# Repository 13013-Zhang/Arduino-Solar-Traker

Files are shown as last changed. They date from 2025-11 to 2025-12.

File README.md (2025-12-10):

Read this in other languages: [English](README.md), [中文](README_ZH.md).

# ES2C6-Solar-Tracker






This is a solar tracker repository for the ES2C6 course. This project includes two distinct Arduino implementations to demonstrate and compare different solar tracking strategies.

1.  **Simple LDR**: A pure "active" tracker that uses four LDRs (Light Dependent Resistors) to find the brightest light source.
2.  **Advanced Hybrid + Web UI Tracker**: A "hybrid" tracker that uses an Arduino R4 WiFi to fetch precise UTC time, calculate the sun's astronomical position (azimuth/elevation), and then uses LDRs for fine-tuning. It also hosts a modern Web UI for status monitoring.

### Circuit
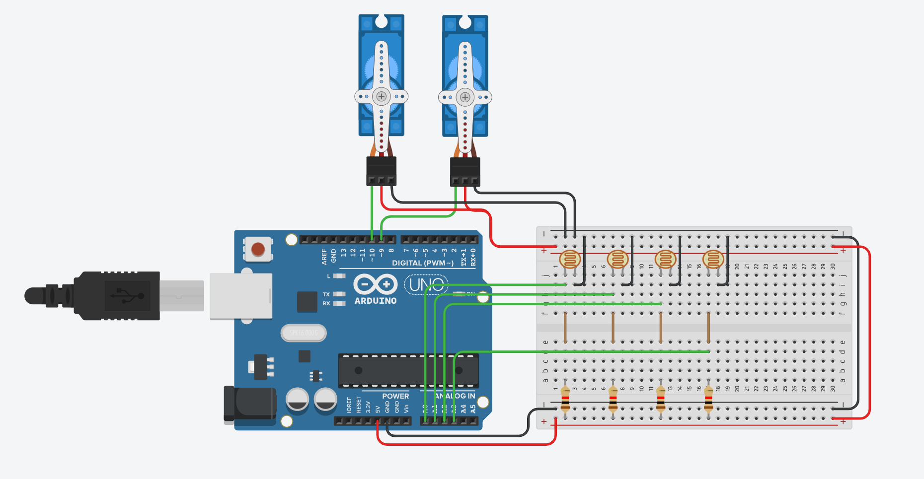
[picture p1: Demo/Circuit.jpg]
Circuit

Schematic

---

## 1. Simple LDR LED Tracker

This is a classic "active" solar tracker. It doesn't care about time or location; it only cares where the light is coming from.

### ✨ Features

* **Active Tracking**: Purely based on the difference in readings from the four LDRs to move the servos, always pointing towards the brightest direction.
    * Solar panel voltage
    * Raw readings of the 4 LDRs
    * Current servo angles (Horizontal/Vertical)
    * Average light intensity
* **Startup Scan**: Executes a `findMaxLightPosition()` function on boot, scanning the sky (0-180 degrees) to find the initial brightest spot.
* **Voltage Monitoring**: Optionally connect a small solar panel to pin `A4` to monitor its output voltage.

### 🛠️ Hardware Requirements

* Arduino Uno / Nano (or any compatible board)
* 2x Servo Motors (for Pan/Tilt)
* 4x LDRs (Light Dependent Resistors)
* 4x Pull-down Resistors (e.g., 10KΩ)
* 1x Small Solar Panel (for A4 pin reading)
* 2-axis Pan/Tilt bracket
* Breadboard and jumper wires

### 📚 Library Dependencies

* `Servo`
* `Adafruit_SSD1306`
* `Adafruit_GFX`

### 🔧 Setup and Usage

1.  Download the code into the `Codes/sdynamic_Step/` folder.
2.  Open `sdynamic_Step.ino` in the Arduino IDE.
3.  Install the `Adafruit_SSD1306` and `Adafruit_GFX` libraries using the Library Manager.
4.  **Check Pins**: Ensure your OLED and servo pin definitions match the `#define` section at the top of the code.
    * OLED (SPI): `OLED_MOSI`, `OLED_CLK`, `OLED_DC`, `OLED_CS`, `OLED_RESET`
    * Servos: `5` (horizontal), `6` (vertical)
    * LDRs: `A0` (TL), `A1` (TR), `A2` (BL), `A3` (BR)
    * Solar Panel: `A4`
5.  Upload the code to your Arduino.
6.  When the device boots, it will first perform a "find max light" scan. The OLED will then light up with real-time data, and the tracker will begin active tracking.

### Demo
- not assembled  
Solar Tracker

---

## 2. Advanced Hybrid + Web UI Tracker

This version uses an Arduino R4 WiFi board, combining time-based predictive tracking with LDR-based corrective tracking.

### ✨ Features

* **Hybrid Tracking**:
    * **Predictive**: Connects to `worldtimeapi.org` to get UTC time and accurately calculates the sun's Azimuth and Elevation based on a given Latitude and Longitude.
    * **Corrective**: Uses a 4-quadrant LDR sensor array to fine-tune the calculated position, compensating for any misalignments or atmospheric effects.
* **Web Console**: Hosts a web server that provides a modern, responsive dashboard built with Tailwind CSS.
* **Solunar API**: Fetches the day's sunrise, sunset, and solar noon times from `api.sunrise-sunset.org`.
* **Night Mode**: Automatically enters "Night Mode" when the sun's elevation is below a threshold (e.g., after sunset), moving the servos to a preset night position (e.g., facing east, ready for sunrise).
* **WiFi Management**: Automatically attempts to reconnect to WiFi if the connection is lost.

### 🛠️ Hardware Requirements

* Arduino R4 WiFi
* 2x Servo Motors (for Pan/Tilt)
* 4x LDRs (Light Dependent Resistors)
* 4x Pull-down Resistors (e.g., 10KΩ)
* 2-axis Pan/Tilt bracket
* Breadboard and jumper wires

### 📚 Library Dependencies

* `WiFiS3`
* `ArduinoJson`
* `Servo`

### 🔧 Setup and Usage

1.  Download the code into the `Codes/Dynamic_Step_wtih_Website/` folder.
2.  Open `dynamic_Step_wtih_Website.ino` in the Arduino IDE.
3.  Install the required libraries using the Library Manager.
4.  **Crucial Configuration**: Modify the constants at the top of the sketch:
    * `WIFI_SSID`: Your WiFi network name.
    * `WIFI_PASS`: Your WiFi password.
    * `LATITUDE`: Your geographic latitude (e.g., `52.378753f`).
    * `LONGITUDE`: Your geographic longitude (e.g., `-1.570225f`).
5.  Upload the code to your Arduino R4 WiFi.
6.  Open the **Serial Monitor** (Baud Rate: 115200) to view the connection status and the IP address.
7.  On a device on the same network, open a web browser and navigate to that IP address (e.g., `http://192.168.31.166`) to see the web console.

### Demo
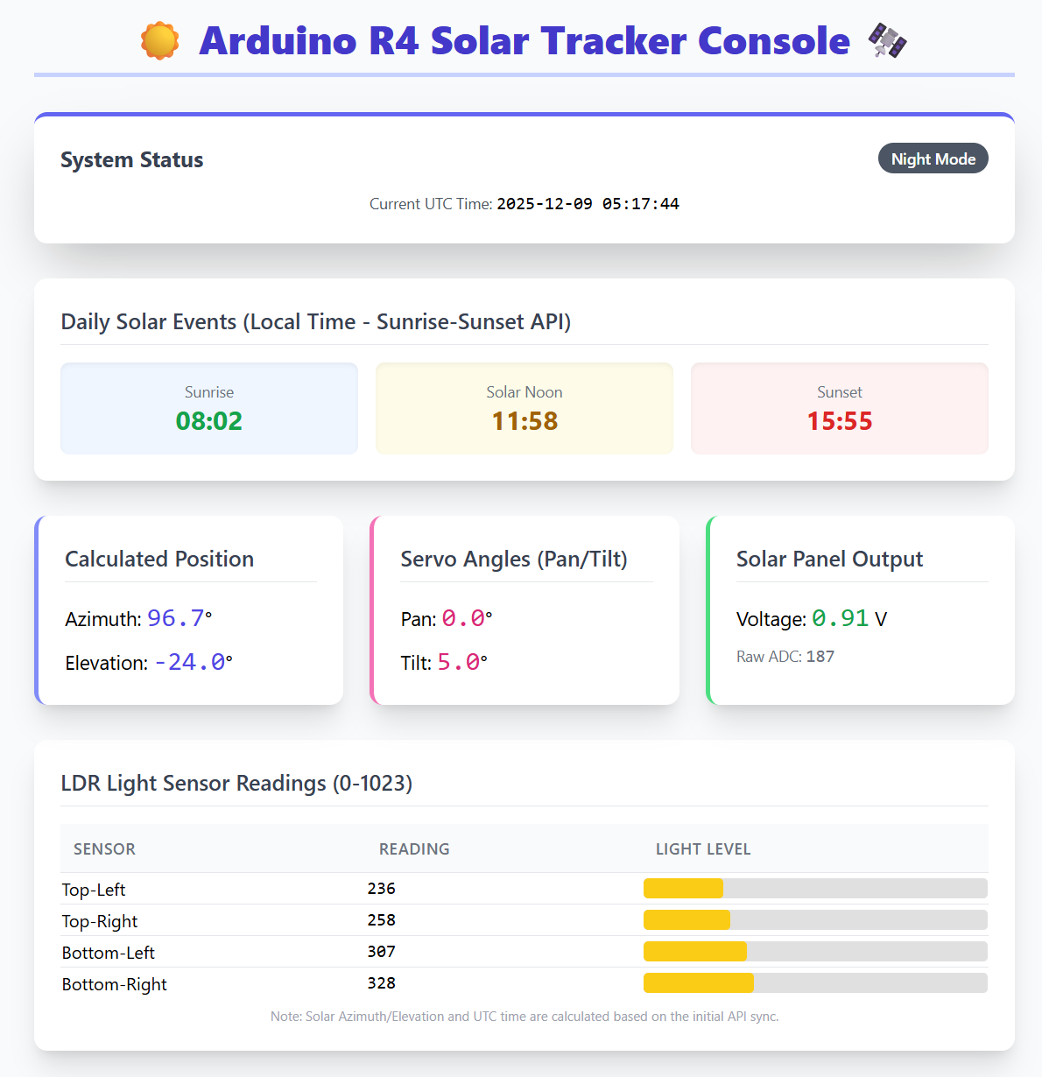
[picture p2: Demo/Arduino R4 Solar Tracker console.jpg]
Solar Tracker


---

## 💡 How It Works

### Active Tracker (Simple)

This model uses a simple **Feedback Loop**:

1.  Compare the average of the top LDRs vs. the average of the bottom LDRs (`diffVertical`).
2.  Compare the average of the left LDRs vs. the average of the right LDRs (`diffHorizontal`).
3.  If the vertical difference is greater than the `tolerance`, move the vertical servo up or down.
4.  If the horizontal difference is greater than the `tolerance`, move the horizontal servo left or right.
5.  This process repeats, constantly minimizing the LDR differences to stay pointed at the light source.

### Hybrid Tracker (Advanced)

This model uses a **Predict-Correct** loop:

1.  **Predict (Every 10 seconds)**: The device gets the precise time from an API and uses the `solarPositionUTC` function to calculate the sun's *theoretical* position in the sky (azimuth/elevation).
2.  **Correct (Every 50 milliseconds)**:
    * The LDRs read the light differential (`azDiff`, `elDiff`).
    * The new target position for the servo is a combination of **(LDR correction) + (a gentle pull towards the theoretical position)**.
    * `currentPan += deltaPan + SOLAR_CORRECTION_RATE * (targetPanFromSolar - currentPan);`
    * This ensures the tracker not only points accurately at the sun (LDR part) but also knows where the sun *should* be, even after it's temporarily hidden by clouds (time-based part).

---

## 🎉 Acknowledgements / Group Members

This project was a collaborative effort for the ES2C6 module, and the successful outcome is a result of the dedicated work of the entire team. We extend our sincere thanks to the following members:

| Name | Assigned Role |
| :--- | :--- |
| Monteiro, Marcus | Background Research |
| Zhao, Haoxiang Owen | Mechanical Design and CAD Work |
| Jackson, Josh | Electronic Design |
| Stephan, Freddy | Manufacture of Mechanical Components and Electronic Circuit Boards |
| Maini, Rohan | Assembly |
| Boyu Zhang Bob (me) | Programming and Testing |
| Charusirisawad, Pun | Overall Project Management and Assigned Task Lead |

---

## 📄 License

This project is licensed under the [MIT License](LICENSE). You should add a `LICENSE` file to your repository.

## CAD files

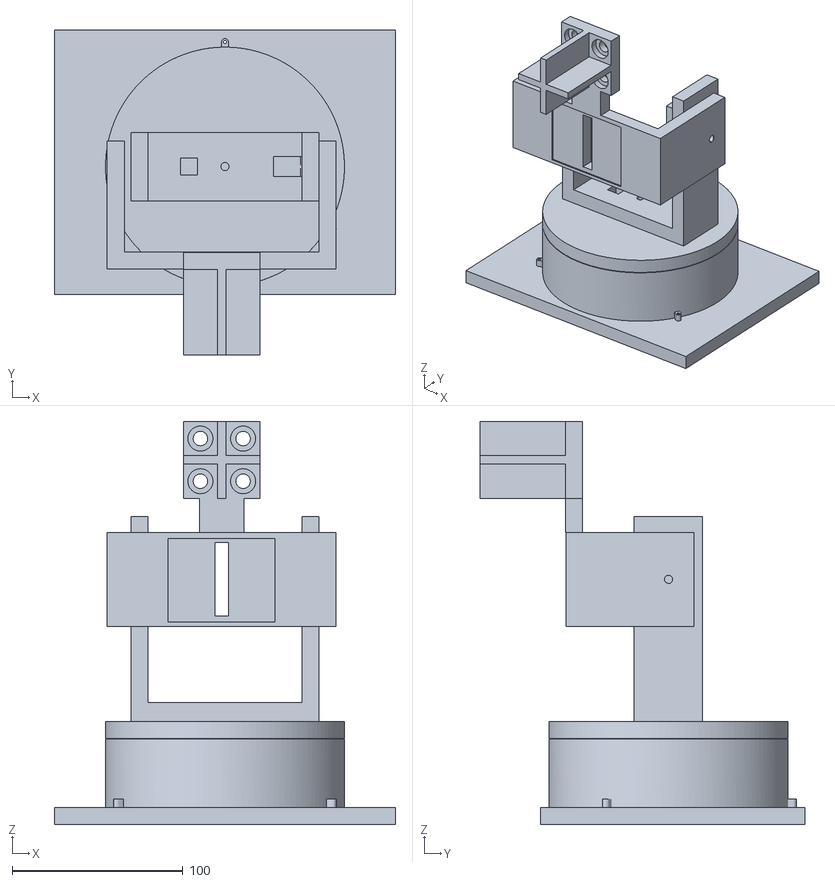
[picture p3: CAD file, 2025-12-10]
3D Printing/Demo 3/Complete.stl
200.0 x 190.4 x 236.1

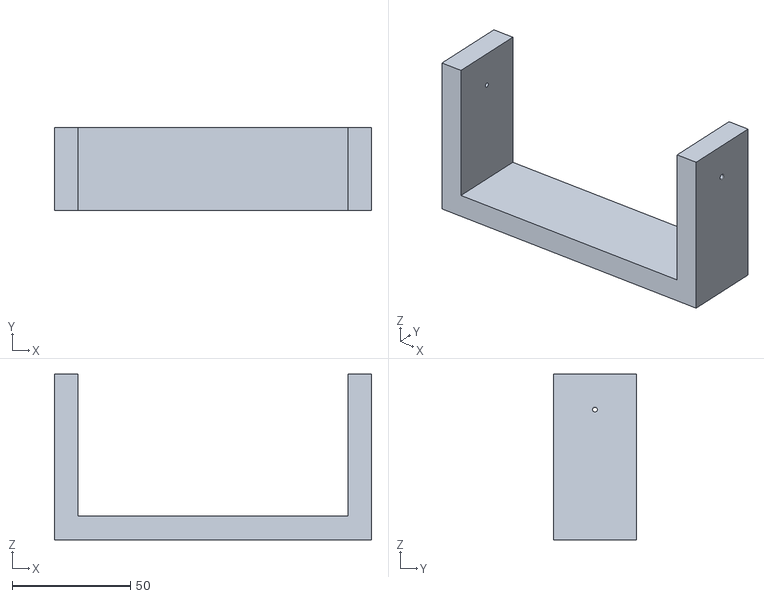
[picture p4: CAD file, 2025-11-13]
3D Printing/Demo 1/Solar Platform.stl
134.0 x 35.0 x 70.0

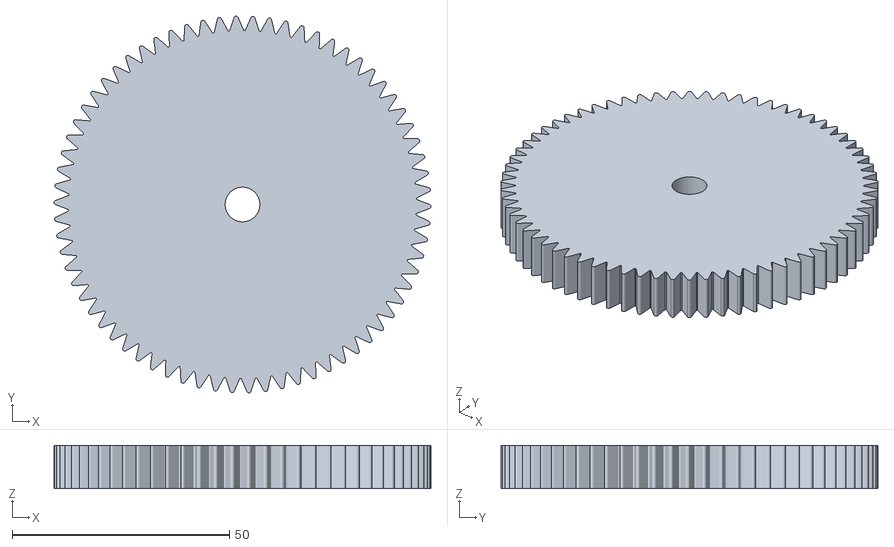
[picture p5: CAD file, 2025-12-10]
3D Printing/Demo 2 Change/Gear median 1 1.stl
86.7 x 86.6 x 10.0

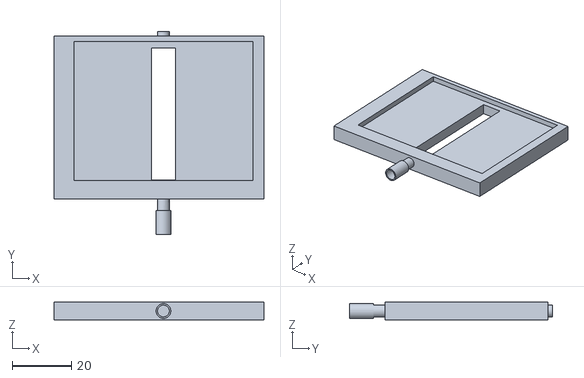
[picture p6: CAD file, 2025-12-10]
3D Printing/Demo 2/Solar Platform Leftside 2. NEW stl.stl
71.0 x 68.5 x 6.00

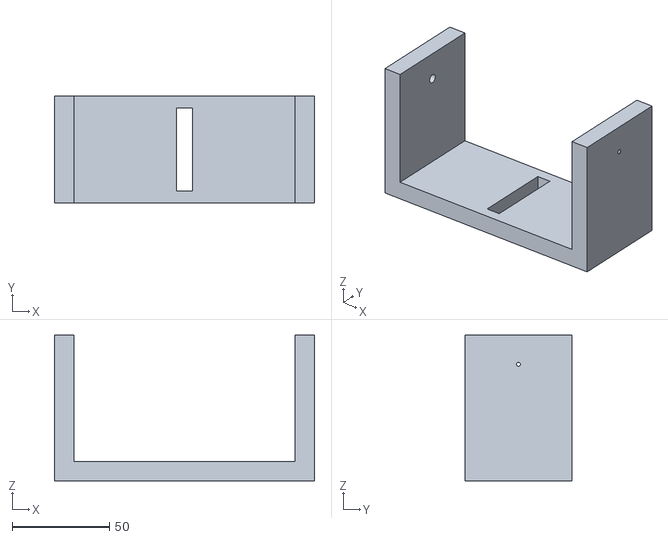
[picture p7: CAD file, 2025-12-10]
3D Printing/Demo 3/Solar Platform 1.stl
134.0 x 55.0 x 75.0

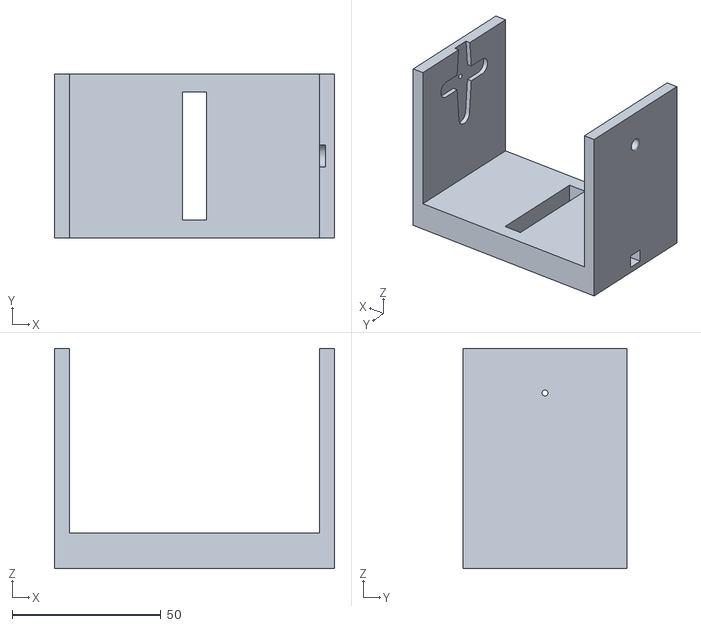
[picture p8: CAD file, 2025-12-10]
3D Printing/Final 1/Solar Platform 2.stl
94.0 x 55.0 x 74.0

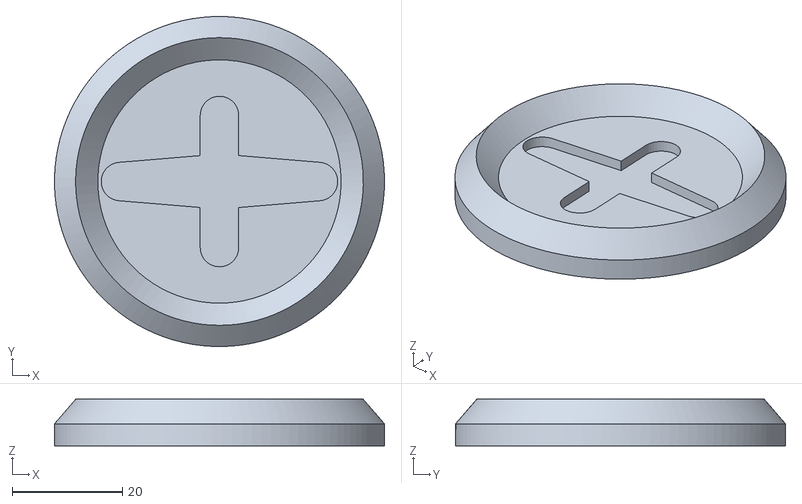
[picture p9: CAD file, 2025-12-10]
3D Printing/Final 2/Base.stl
60.0 x 60.0 x 8.46

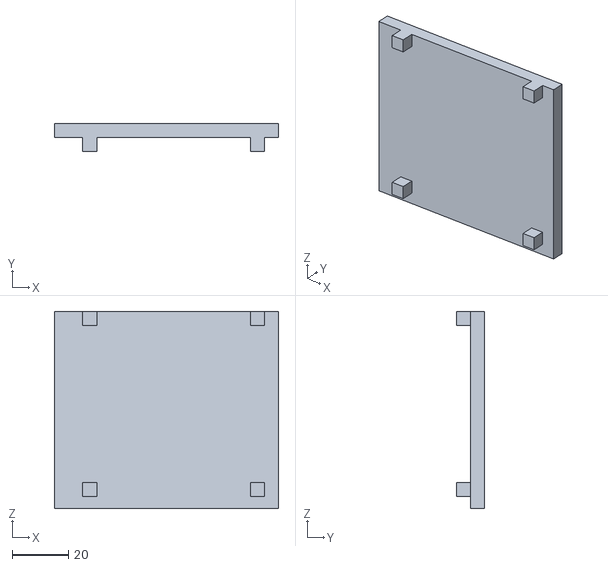
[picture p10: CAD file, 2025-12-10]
3D Printing/Final 3/Walls.stl
79.5 x 10.0 x 70.0

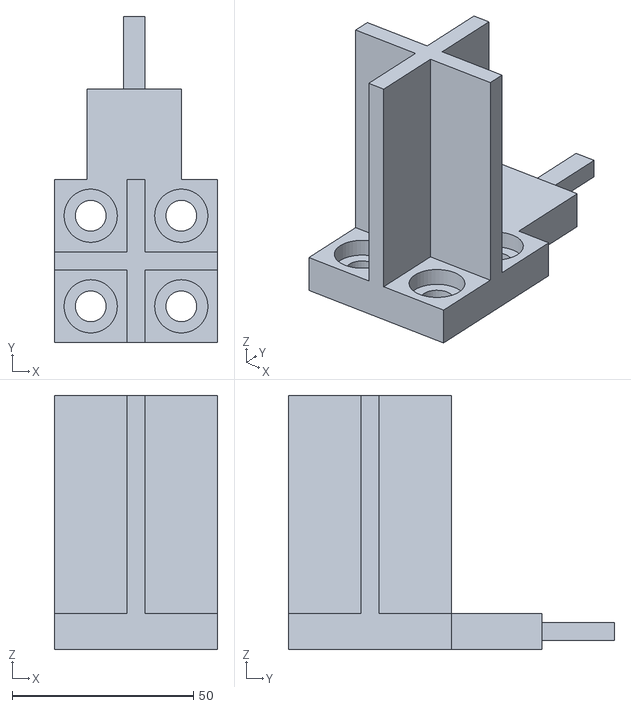
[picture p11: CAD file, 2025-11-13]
3D Printing/Demo 1/LDR Platform.stl
45.0 x 90.0 x 70.1

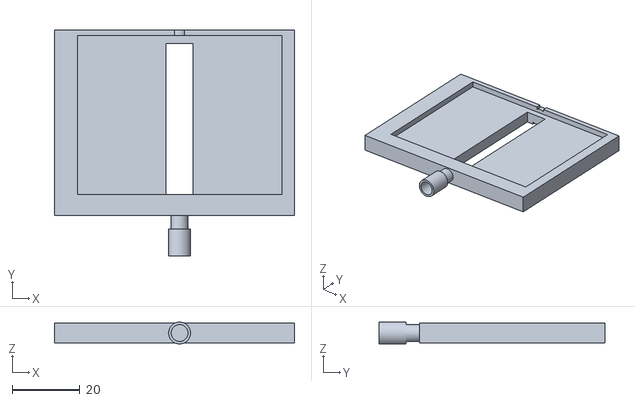
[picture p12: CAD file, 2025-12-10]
3D Printing/Demo 2 Change/Solar Platform Leftside 2 2.stl
71.0 x 67.0 x 6.49

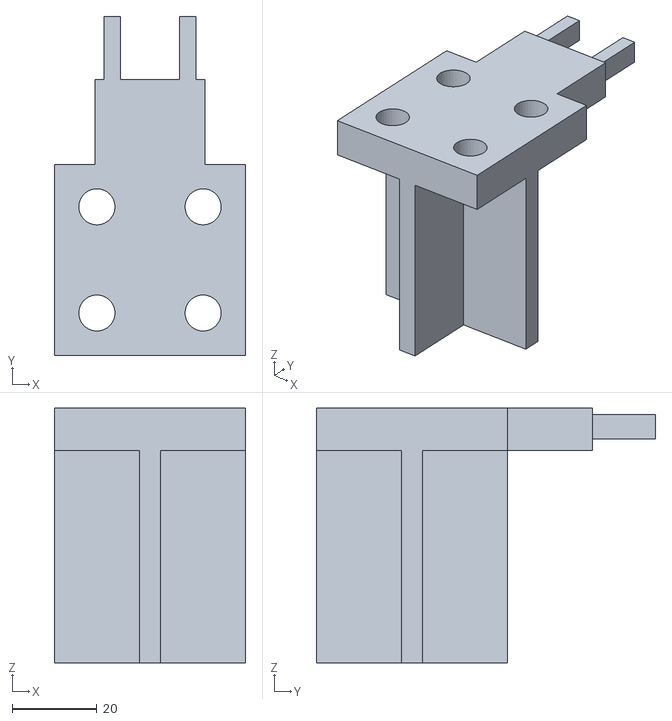
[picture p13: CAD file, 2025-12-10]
3D Printing/Demo 3/LDR.stl
45.0 x 79.8 x 60.0

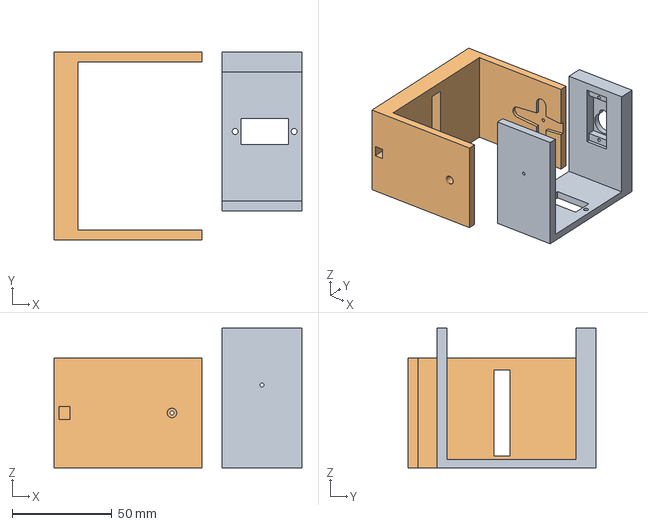
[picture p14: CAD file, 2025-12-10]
3D Printing/Final 1/Final 1.3mf
124.0 x 94.0 x 70.0 mm
Motor circuling Platform 2.stl
Solar Platform 2.stl

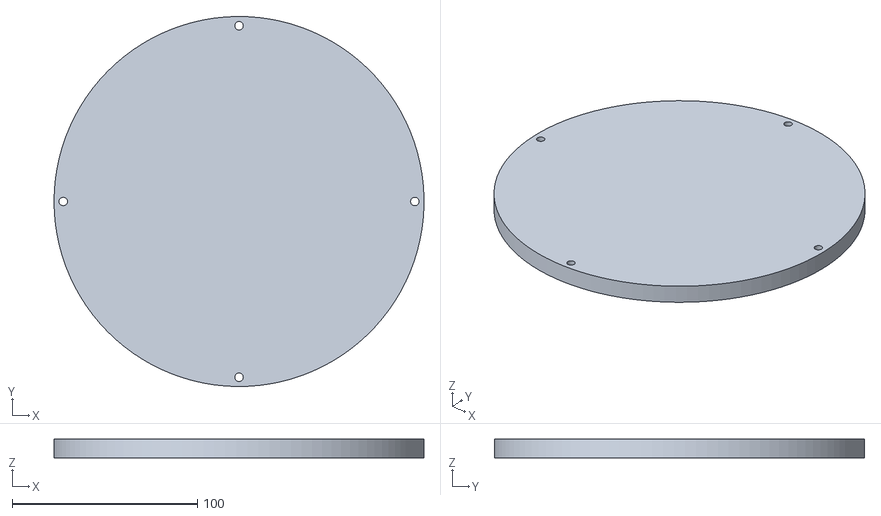
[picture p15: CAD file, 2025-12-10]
3D Printing/Final 2/Lower Base Connector.stl
200.0 x 200.0 x 10.0

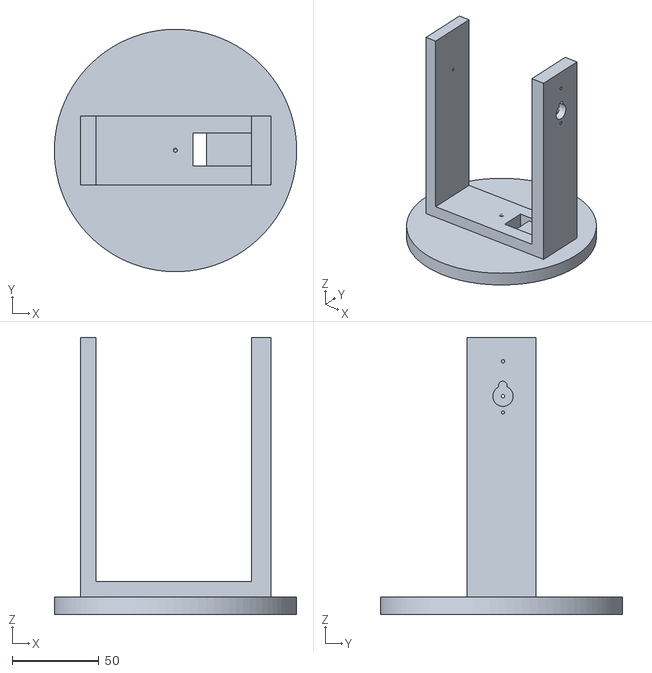
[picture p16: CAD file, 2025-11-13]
3D Printing/Demo 1/Motor circuling Platform.stl
140.0 x 140.0 x 160.0

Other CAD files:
3D Printing/Demo 2/Solar Platform Leftside 2 1.stl
3D Printing/Final 3/Walls 2.stl
3D Printing/Demo 2 Change/Demo 2 Changed.3mf
3D Printing/Demo 2/LDR Platform Part1 1.stl
3D Printing/Demo 1/LDR Platform.f3d
3D Printing/Demo 1/Motor circuling Platform.f3d
3D Printing/Demo 1/Solar Platform First Edition.3mf
3D Printing/Demo 1/Solar Platform.f3d
3D Printing/Demo 1/Under Platform.f3d
3D Printing/Demo 1/Under Platform.stl
3D Printing/Demo 2 Change/sleve 1.stl
3D Printing/Demo 2/Advancce Edition Motor Platform 1.stl
3D Printing/Demo 2/Demo 2.3mf
3D Printing/Demo 2/First class connecting bar 1.stl
3D Printing/Demo 2/Gear median 1.stl
3D Printing/Demo 2/Gear median thicker 1.stl
3D Printing/Demo 2/LDR Platform Part1 1 1.stl
3D Printing/Demo 2/Solar Platform Leftside 2.stl
3D Printing/Demo 2/Upper Connecting Bar 1.stl
3D Printing/Demo 2/sleve 2.stl
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

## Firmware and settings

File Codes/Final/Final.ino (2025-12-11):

#include <WiFiS3.h> // For Uno R4 WiFi
#include <WiFiClient.h>
#include <WiFiServer.h>
#include <ArduinoJson.h>
#include <Servo.h>

// ----------------------------------------------------------------------------
// 1. CONFIGURATION CONSTANTS
// ----------------------------------------------------------------------------

const char* WIFI_SSID = "Redmi K70 Ultra";
const char* WIFI_PASS = "20050215";


const float LATITUDE = 34.0522; 
const float LONGITUDE = -118.2437; 

// API Hostnames
const char* TIME_HOST = "worldtimeapi.org"; 
const char* SOLUNAR_HOST = "api.sunrise-sunset.org"; 


// LDRs
const int LDR_TL = A0; // Top-Left
const int LDR_TR = A1; // Top-Right
const int LDR_BL = A2; // Bottom-Left
const int LDR_BR = A3; // Bottom-Right
// Solar Panel Voltage Sensor
const int SOLAR_PANEL_PIN = A4; 
// Servos
const int HORIZONTAL_SERVO_PIN = 6; // Pan Servo
const int VERTICAL_SERVO_PIN = 5;   // Tilt Servo
// Manual Override Pin (Low to disable tracking)
const int SERVOS_OFF_PIN = 7; 


// ----------------------------------------------------------------------------
// 2. DATA STRUCTURES
// ----------------------------------------------------------------------------


struct TimeData {
    int Y = 0, M = 0, D = 0, h = 0, min = 0, s = 0;
    String iso_sync = ""; 

    String toString() const {
        char buf[20];
        sprintf(buf, "%04d-%02d-%02d %02d:%02d:%02d", Y, M, D, h, min, s);
        return String(buf);
    }
};

struct SolarAngles {
    float azimuth = 0.0;
    float elevation = 0.0;
};

struct SolunarData {
    String sunrise = "--:--";
    String sunset = "--:--";
    String solarnoon = "--:--";
    int lastFetchDay = 0;
};

// ----------------------------------------------------------------------------
// 3. GLOBAL STATE
// ----------------------------------------------------------------------------

// Web Server
WiFiServer server(80);


TimeData g_currentTime;
SolunarData dailySolunar;
SolarAngles lastSolar; 

Servo horizontalServo;
Servo verticalServo;


int sensitivity = 50; 
const int minStepSize = 2; 


int horizontalPos = 90;
int verticalPos = 90;

int tl = 0;
int tr = 0;
int bl = 0;
int br = 0;

// 太阳能板读数
float slr = 0;
float slrTrue = 0;

// 翻转逻辑 (Flip Timer)
int count = 0;
unsigned long stuckTimerStart = 0;
const int waitTime = 1000; // 1秒等待时间
const int cooldown = 1000; // 1秒冷却时间
unsigned long cooldownStarted = 0;

// 日落逻辑 (Sunset Timer)
int sunsetAngle = 20; // 仰角小于此值时开始判断
int LDRavg = 0;
int sunsetDarkness = 850; // 平均 LDR 读数大于此值时认为天黑
int countSunset = 0;
unsigned long sunsetTimer = 0;
const int sunsetWait = 5000; // 5秒等待时间
const int pauseTimer = 250; // 暂停时间
unsigned long currentTime = 0;


// ----------------------------------------------------------------------------
// 4. UTILITY FUNCTIONS (辅助函数)
// ----------------------------------------------------------------------------

float deg2rad(float deg) {
    return deg * (PI / 180.0);
}

float rad2deg(float rad) {
    return rad * (180.0 / PI);
}

// LDR 读取辅助函数
int readLDR(int pin) {
    return analogRead(pin);
}

// 儒略日计算 (简化版，适用于粗略太阳位置计算)
double calcJulianDay(int Y, int M, int D, int h, int min, int s) {
    double D_h = D + (h + min / 60.0 + s / 3600.0) / 24.0;
    if (M <= 2) {
        Y -= 1;
        M += 12;
    }
    double A = floor(Y / 100.0);
    double B = 2 - A + floor(A / 4.0);
    return floor(365.25 * (Y + 4716)) + floor(30.6001 * (M + 1)) + D_h + B - 1524.5;
}

// 12小时制时间转换为24小时制 HH:MM
String convert12hTo24h(String time12h) {
    if (time12h == "") return "--:--";
    time12h.trim();
    int spaceIndex = time12h.indexOf(' ');
    String timePart = time12h.substring(0, spaceIndex);
    String ampmPart = time12h.substring(spaceIndex + 1);

    int colonIndex = timePart.indexOf(':');
    int hour = timePart.substring(0, colonIndex).toInt();
    int minute = timePart.substring(colonIndex + 1, colonIndex + 3).toInt(); // Extract minutes up to the second colon if seconds exist

    if (ampmPart == "PM" && hour != 12) {
        hour += 12;
    } else if (ampmPart == "AM" && hour == 12) {
        hour = 0; // Midnight 12 AM is 00
    }

    char buf[6];
    sprintf(buf, "%02d:%02d", hour, minute);
    return String(buf);
}


// ----------------------------------------------------------------------------
// 5. SOLAR POSITION CALCULATION (太阳位置计算)
// ----------------------------------------------------------------------------

// 计算给定UTC时间的太阳方位角和仰角 (基于 NOAA 算法的简化版)
SolarAngles solarPositionUTC(const TimeData& t, float lat, float lon) {
    // 您的太阳角度计算逻辑
    double jd = calcJulianDay(t.Y, t.M, t.D, t.h, t.min, t.s);
    double n = jd - 2451545.0;
    double L = fmod(280.460 + 0.9856474 * n, 360.0);
    if (L < 0) L += 360.0;
    double g = fmod(357.528 + 0.9856003 * n, 360.0);
    if (g < 0) g += 360.0;
    double g_rad = deg2rad((float)g);
    double lambda = L + 1.915 * sin(g_rad) + 0.020 * sin(2 * g_rad);
    double lambda_rad = deg2rad((float)lambda);
    double eps = 23.439 - 0.0000004 * n;
    double eps_rad = deg2rad((float)eps);
    double alpha = atan2(cos(eps_rad) * sin(lambda_rad), cos(lambda_rad));
    double delta = asin(sin(eps_rad) * sin(lambda_rad));
    double JD0 = floor(jd + 0.5) - 0.5;
    double T = (JD0 - 2451545.0) / 36525.0;
    double GMST = fmod(280.46061837 + 360.98564736629 * (jd - 2451545.0) + 0.000387933 * T * T - (T * T * T) / 38710000.0, 360.0);
    if (GMST < 0) GMST += 360.0;
    double LST = fmod(GMST + lon, 360.0);
    if (LST < 0) LST += 360.0;
    double alpha_deg = rad2deg((float)alpha);
    if (alpha_deg < 0) alpha_deg += 360.0;
    double H = LST - alpha_deg;
    if (H < -180) H += 360;
    if (H > 180) H -= 360;
    double H_rad = deg2rad((float)H);
    double lat_rad = deg2rad(lat);
    double el_rad = asin(sin(lat_rad) * sin(delta) + cos(lat_rad) * cos(delta) * cos(H_rad));
    double elevation = rad2deg((float)el_rad);
    // 修正的方位角计算 atan2(sin(H), cos(H) * sin(lat) - tan(delta) * cos(lat))
    double az_rad = atan2(sin(H_rad), cos(H_rad) * sin(lat_rad) - tan(delta) * cos(lat_rad));
    double az_deg = rad2deg((float)az_rad);
    // 将方位角调整到 0 到 360 度范围，0度为北，180度为南 (NOAA标准: 南为0)
    // 转换为标准方位角 (北为0, 东为90)
    az_deg = az_deg + 180.0; 
    if (az_deg < 0) az_deg += 360.0;
    if (az_deg >= 360) az_deg -= 360.0;
    
    SolarAngles out;
    out.azimuth = (float)az_deg;
    out.elevation = (float)elevation;
    return out;
}


// ----------------------------------------------------------------------------
// 6. NETWORK AND API FUNCTIONS (网络与 API)
// ----------------------------------------------------------------------------

bool attemptReconnect(unsigned long timeout_ms) {
    if (WiFi.status() == WL_CONNECTED && WiFi.localIP() != IPAddress(0, 0, 0, 0)) {
        return true;
    }
    Serial.println("\nAttempting Wi-Fi reconnect...");
    WiFi.disconnect();
    WiFi.begin(WIFI_SSID, WIFI_PASS);
    unsigned long start = millis();
    while (WiFi.status() != WL_CONNECTED && millis() - start < timeout_ms) {
        delay(500);
        Serial.print("#");
    }
    if (WiFi.status() == WL_CONNECTED && WiFi.localIP() != IPAddress(0, 0, 0, 0)) {
        Serial.println("\nReconnect successful. IP: " + WiFi.localIP().toString());
        server.begin();
        return true;
    }
    Serial.println("\nWi-Fi reconnect failed.");
    return false;
}

bool fetchUTC(TimeData& t) {
    WiFiClient client;
    Serial.print("Attempting to connect to Time API (");
    Serial.print(TIME_HOST);
    Serial.print(")...");

    if (!client.connect(TIME_HOST, 80)) {
        Serial.println("Connection failed!");
        return false;
    }
    Serial.println("Success!");

    String req = "GET /api/ip HTTP/1.1\r\nHost: ";
    req += TIME_HOST;
    req += "\r\nConnection: close\r\n\r\n";
    client.print(req);

    unsigned long start = millis();
    while (!client.available() && millis() - start < 10000) delay(10);

    if (!client.available()) {
        Serial.println("API response timeout.");
        client.stop();
        delay(100);
        return false;
    }

    // Skip HTTP headers
    while (client.available()) {
        String line = client.readStringUntil('\n');
        if (line.length() < 3 && line.indexOf('\r') != -1) break;
    }

    String json = client.readString();
    client.stop();
    delay(100);

    if (json.length() < 50) {
        Serial.println("API response too short or invalid.");
        return false;
    }

    // 假设 DynamicJsonDocument size 足够
    DynamicJsonDocument doc(1024);
    DeserializationError error = deserializeJson(doc, json);

    if (error) {
        Serial.print("UTC JSON parsing error: ");
        Serial.println(error.c_str());
        return false;
    }

    if (!doc.containsKey("utc_datetime")) {
        Serial.println("UTC JSON missing 'utc_datetime' field.");
        return false;
    }

    String dt = doc["utc_datetime"].as<String>();
    // 格式: 2023-11-20T10:30:00.123456+00:00 (只取前19位)
    
    // 检查 T 在正确的位置
    if (dt.indexOf('T') != 10) {
        Serial.println("UTC datetime format error.");
        return false;
    }

    t.iso_sync = dt.substring(0, 19); 
    t.Y = dt.substring(0, 4).toInt();
    t.M = dt.substring(5, 7).toInt();
    t.D = dt.substring(8, 10).toInt();
    t.h = dt.substring(11, 13).toInt();
    t.min = dt.substring(14, 16).toInt();
    t.s = dt.substring(17, 19).toInt();

    Serial.print("Successfully synced UTC time: ");
    Serial.println(t.toString());
    return true;
}

bool fetchSolunar(const TimeData& t) {
    if (t.Y == 0) {
        Serial.println("Solunar Fetch: UTC time not synced, skipping fetch.");
        return false;
    }
    if (t.D == dailySolunar.lastFetchDay && dailySolunar.sunrise != "--:--") {
        Serial.println("Solunar Fetch: Data for today already fetched, skipping.");
        return true;
    }

    WiFiClient client;
    Serial.print("Attempting to connect to Solunar API (");
    Serial.print(SOLUNAR_HOST);
    Serial.print(")...");

    if (!client.connect(SOLUNAR_HOST, 80)) {
        Serial.println("Connection failed!");
        return false;
    }
    Serial.println("Success!");

    char dateStr[11];
    sprintf(dateStr, "%04d-%02d-%02d", t.Y, t.M, t.D);
    String latStr = String(LATITUDE, 7);
    String lngStr = String(LONGITUDE, 7);
    // API默认返回本地时间
    String path = "/json?lat=" + latStr + "&lng=" + lngStr + "&date=" + String(dateStr); 

    Serial.print("Solunar Request URL: http://");
    Serial.print(SOLUNAR_HOST);
    Serial.println(path);


    client.print("GET ");
    client.print(path);
    client.print(" HTTP/1.1\r\n");
    client.print("Host: " + String(SOLUNAR_HOST) + "\r\n");
    client.print("Connection: close\r\n\r\n");

    String json = "";
    unsigned long startJsonRead = millis();
    bool header_passed = false;

    while (client.connected() && millis() - startJsonRead < 8000) { // Timeout 8s
        if (client.available()) {
            String line = client.readStringUntil('\n');
            if (!header_passed) {
                if (line == "\r") { // End of headers
                    header_passed = true;
                }
            } else {
                json += line; // Start reading JSON body
            }
        } else {
            delay(10);
        }
    }
    client.stop();
    delay(100);
    
    // Attempt to find the first '{' to ensure clean JSON parsing
    int jsonStart = json.indexOf('{');
    if (jsonStart != -1) {
        json = json.substring(jsonStart);
    } else {
        Serial.println("API response missing JSON content.");
        return false;
    }


    Serial.print("Solunar RAW JSON (Length: ");
    Serial.print(json.length());
    Serial.println("):");
    // Serial.println(json); // 打印原始JSON可能太长，只打印长度

    if (json.length() < 50) {
        Serial.println("API response too short or invalid.");
        return false;
    }

    DynamicJsonDocument doc(2048);
    DeserializationError error = deserializeJson(doc, json);

    if (error) {
        Serial.print("Solunar JSON error: ");
        Serial.println(error.c_str());
        return false;
    }

    String status = doc["status"].as<String>();
    if (status != "OK" || !doc.containsKey("results")) {
        Serial.print("Solunar API returned non-OK status: ");
        Serial.println(status);
        return false;
    }

    // API 返回 12 小时制带 AM/PM 的时间
    String rawSunrise = doc["results"]["sunrise"].as<String>();
    String rawSunset = doc["results"]["sunset"].as<String>();
    String rawSolarNoon = doc["results"]["solar_noon"].as<String>();

    // 转换为 24 小时制 HH:MM
    dailySolunar.sunrise = convert12hTo24h(rawSunrise);
    dailySolunar.sunset = convert12hTo24h(rawSunset);
    dailySolunar.solarnoon = convert12hTo24h(rawSolarNoon);
    dailySolunar.lastFetchDay = t.D;

    Serial.println("Solunar data updated successfully (from api.sunrise-sunset.org)");
    return true;
}


// ----------------------------------------------------------------------------
// 7. WEB SERVER FUNCTIONS (Web 服务器)
// ----------------------------------------------------------------------------

String buildStatusJSON() {
    DynamicJsonDocument doc(1024);
    doc["lat"] = LATITUDE;
    doc["lon"] = LONGITUDE;

    if (g_currentTime.Y != 0) {
        // 由于 Arduino 没有实时RTC，所以时间只是首次同步的值
        doc["utc"] = g_currentTime.toString(); 
        doc["timestamp_sync"] = g_currentTime.iso_sync; 
    } else {
        doc["utc"] = "Time Sync Failed";
    }

    // 强制设置为 LDR 跟踪模式
    doc["mode"] = "LDR Tracking Mode (Always Active)"; 

    // 天文数据 (初始计算值)
    doc["solar"]["azimuth"] = roundf(lastSolar.azimuth * 10.0f) / 10.0f;
    doc["solar"]["elevation"] = roundf(lastSolar.elevation * 10.0f) / 10.0f;

    // 日出日落数据
    doc["solunar"]["sunrise"] = dailySolunar.sunrise;
    doc["solunar"]["sunset"] = dailySolunar.sunset;
    doc["solunar"]["solarnoon"] = dailySolunar.solarnoon;

    // 伺服角度 (使用控制逻辑中的实时位置)
    doc["servos"]["pan"] = roundf(horizontalPos * 10.0f) / 10.0f;
    doc["servos"]["tilt"] = roundf(verticalPos * 10.0f) / 10.0f;

    // LDR 读数
    doc["ldr"]["tl"] = tl;
    doc["ldr"]["tr"] = tr;
    doc["ldr"]["bl"] = bl;
    doc["ldr"]["br"] = br;

    // 太阳能板输出
    doc["solar_panel"]["voltage"] = roundf(slrTrue * 100.0f) / 100.0f;
    doc["solar_panel"]["raw"] = (int)slr;

    String out;
    serializeJson(doc, out);
    return out;
}

void handleClient(WiFiClient client) {
    // Web Server HTML/JSON 逻辑
    String req = client.readStringUntil('\r');
    if (req.length() < 2) {
        client.stop();
        return;
    }
    int sp1 = req.indexOf(' '), sp2 = req.indexOf(' ', sp1 + 1);
    String path = req.substring(sp1 + 1, sp2);
    
    // Read the rest of the HTTP request headers
    while (client.available()) {
        String line = client.readStringUntil('\n');
        if (line == "\r") break;
    }

    if (path == "/") {
        // HTML Content - 仅保留伺服角度、太阳能板输出和 LDR 读数
        String html = R"rawliteral(
<!doctype html>
<html>
<head>
<meta charset='utf-8'>
<meta name="viewport" content="width=device-width, initial-scale=1.0">
<title>Solar Tracker Console</title>
<script src="https://cdn.tailwindcss.com"></script>
<style>
@import url('https://fonts.googleapis.com/css2?family=Inter:wght@100..900&display=swap');
body { 
    font-family: 'Inter', sans-serif; 
    background-color: #f7f9fc;
}
.ldr-bar-container { 
    height: 18px; 
    background: #e0e0e0; 
    border-radius: 4px; 
    overflow: hidden; 
    margin: 4px 0; 
}
.ldr-bar { 
    height: 100%; 
    transition: width 0.3s ease-out; 
    border-radius: 4px; 
}
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
void loop() {
    // 1. Web Server Client Handling
    WiFiClient client = server.available();
    if (client) {
        handleClient(client);
    }

    // 2. Control System Logic (LDRs and Servos)
    
    // LDR reading
    tl = analogRead(LDR_TL);
    tr = analogRead(LDR_TR);
    bl = analogRead(LDR_BL);
    br = analogRead(LDR_BR);

    // Solar reading
    slr = analogRead(SOLAR_PANEL_PIN);
    slrTrue = slr * (5.0 / 1023.0); // 转换为电压 (假设 5V 参考电压)

    // 检查手动关闭开关 (SERVOS_OFF_PIN 低电平有效)
    if (digitalRead(SERVOS_OFF_PIN) == LOW) {
        // 保持在中心位置且不移动
        verticalPos = 90;
        horizontalPos = 90;
        verticalServo.write(verticalPos);
        horizontalServo.write(horizontalPos);
        Serial.println("--- Servos Disabled (Pin 7 LOW) ---");
        delay(500); // 降低循环频率
        return; // 跳过控制和日志输出
    }


    // Horizontal calculations (Pan)
    int errorHorizontal = (tl + bl) / 2 - (tr + br) / 2;
    int horizontalStep = calculateDynamicStep(errorHorizontal);

    // 从 Servo 读取当前位置 (虽然我们用变量跟踪，但这里确保同步)
    horizontalPos = horizontalServo.read();

    // 调整水平步长
    if (abs(errorHorizontal) < sensitivity) horizontalStep = 0;
    if (errorHorizontal < 0) horizontalStep = -horizontalStep; // 负误差表示向右 (TR/BR 大)

    // 垂直翻转校正 (如果垂直舵机超过 90 度，意味着面板倒置，水平方向需反转)
    if (verticalPos > 90) horizontalStep = -horizontalStep;


    // Vertical Servo control (Tilt)
    int errorVertical = (tl + tr) / 2 - (bl + br) / 2;
    int verticalStep = calculateDynamicStep(errorVertical);

    verticalPos = verticalServo.read();

    // 调整垂直步长
    if (abs(errorVertical) < sensitivity) verticalStep = 0;
    // 垂直舵机通常是向上 (大读数在 Top LDRs) 移动，这里是反向控制 (垂直轴与水平轴方向相反)
    if (errorVertical < 0) verticalStep = -verticalStep; // 负误差表示向下 (BL/BR 大)


    // 3. Flip Code (180度翻转逻辑)
    // 检查水平移动是否超出限制 (0-180度)
    if ((horizontalPos + horizontalStep > 180) || (horizontalPos + horizontalStep < 0)) {
        if (count == 0) {
            // 检查冷却时间
            if (millis() < cooldownStarted + cooldown) {
                Serial.println("On cooldown!");
            } else {
                // 启动翻转计时器
                stuckTimerStart = millis();
                count = 1;
                Serial.println("-------------------");
                Serial.println("Flip Timer Started!");
                Serial.println("-------------------");
            }
        } else {
            // 计时器已启动，检查是否超时
            if (millis() >= stuckTimerStart + waitTime) {
                // 执行翻转
                horizontalPos = 180 - horizontalPos; // 水平反转
                horizontalStep = 0;
                verticalPos = 180 - verticalPos;     // 垂直反转
                verticalStep = 0;

                Serial.println("--------------------");
                Serial.println("Flipping the script!");
                Serial.println("--------------------");


                currentTime = millis();
                while (millis() < currentTime + pauseTimer) {} 
                cooldownStarted = millis(); 
                count = 0;  
                stuckTimerStart = 0;
            }
        }
    } else {
        // 如果之前启动了计时器，但现在不再超出限制，则重置计时器
        if (count == 1) {
            count = 0;
            stuckTimerStart = 0;
        }
    }


    // 4. Sunset Code (日落逻辑)
    LDRavg = (tl + tr + bl + br) / 4;

    // 条件: 仰角够低 AND LDR 平均值够高 (天黑)
    if (((verticalServo.read() <= sunsetAngle) || (verticalServo.read() >= 180 - sunsetAngle)) && (LDRavg >= sunsetDarkness)) {
        if (countSunset == 0) {
            // 启动日落计时器
            sunsetTimer = millis();
            countSunset = 1;
            Serial.println("----------------");
            Serial.println("Possible Sunset!");
            Serial.println("----------------");
        } else {
            if (millis() >= sunsetTimer + sunsetWait) {
                // 日落确认，移动到夜间位置 (45度或 135度)
                countSunset = 0;
                sunsetTimer = 0;

                Serial.println("----------------------------");
                Serial.println("Sunset Confirmed! Goodnight!");
                Serial.println("----------------------------");
                
                // 短暂暂停以便串口输出
                currentTime = millis();
                while (millis() < currentTime + pauseTimer) {} 

                if (verticalServo.read() <= sunsetAngle) {
                    verticalPos = 135; // 移动到一侧的 45 度角 (90 + 45)
                } else {
                    verticalPos = 45;  // 移动到另一侧的 45 度角 (90 - 45)
                }
                verticalStep = 0;
                horizontalStep = 0; // 停止水平移动
            }
        }
    } else {
        // 如果条件不再满足，重置日落计时器
        if (countSunset == 1) {
            Serial.println("-------------------------------");
            Serial.println("Sunset Unconfirmed! Staying up!");
            Serial.println("-------------------------------");

            countSunset = 0;
            sunsetTimer = 0;
        }
    }

    // 5. Servo Movement
    horizontalPos = constrain(horizontalPos + horizontalStep, 0, 180);
    horizontalServo.write(horizontalPos);

    verticalPos = constrain(verticalPos - verticalStep, 0, 180); 
    verticalServo.write(verticalPos);

    
    // 6. Serial Debug Output
    
    Serial.print("TL:");
    Serial.print(tl);
    Serial.print(" | TR:");
    Serial.print(tr);
    Serial.print(" | BL:");
    Serial.print(bl);
    Serial.print(" | BR:");
    Serial.print(br);

    Serial.print(" | H_Err:");
    Serial.print(errorHorizontal);
    Serial.print(" | H_Step:");
    Serial.print(horizontalStep);
    Serial.print(" | H_Pos:");
    Serial.print(horizontalPos);

    Serial.print(" | V_Err:");
    Serial.print(errorVertical);
    Serial.print(" | V_Step:");
    Serial.print(verticalStep);
    Serial.print(" | V_Pos:");
    Serial.print(verticalPos);

    Serial.print(" | V_Slr:");
    Serial.print(slrTrue);
    Serial.print("V");

    // 状态提示
    if (count == 1) {
        Serial.print(" | Flip Active!");
    }
    if (millis() < cooldownStarted + cooldown) {
        Serial.print(" | Flip Cooldown!");
    }
    if (countSunset == 1) {
        Serial.print(" | Checking Sunset!");
    }
    Serial.println();
    
    // 7. Obligatory delay
    delay(30);
}

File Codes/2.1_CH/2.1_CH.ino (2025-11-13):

#include <WiFiS3.h>
#include <WiFiClient.h>
#include <Servo.h>
#include <ArduinoJson.h>
#include <math.h>

// --- LDR & SERVO PINS ---
#define LDR_TL A0 // 光敏电阻：左上
#define LDR_TR A1 // 光敏电阻：右上
#define LDR_BL A2 // 光敏电阻：左下
#define LDR_BR A3 // 光敏电阻：右下

#define PAN_SERVO_PIN 5 // 水平舵机引脚
#define TILT_SERVO_PIN 6 // 俯仰舵机引脚

// --- WIFI CONFIGURATION (直接定义凭证，不使用 arduino_secrets.h) ---
const char* WIFI_SSID = "Free_WiFi"; 
const char* WIFI_PASS = "Bob@1357924680";

// --- LOCATION (使用 float) ---
const float LATITUDE = 52.378753f;
const float LONGITUDE = -1.570225f;

// --- API HOSTS ---
const char* SOLUNAR_HOST = "api.sunrise-sunset.org";
const char* TIME_HOST = "worldtimeapi.org"; 

// --- TRACKING CONSTANTS (使用 float 后缀 'f') ---
const float AZ_GAIN = 0.015f;
const float EL_GAIN = 0.015f;
const float LDR_DEAD_BAND = 15.0f;
const float SOLAR_CORRECTION_RATE = 0.005f;

const float NIGHT_MODE_THRESHOLD = -2.0f; 
const float TILT_MAX = 90.0f;
const float TILT_MIN = 0.0f;
const float PAN_MAX = 180.0f;
const float PAN_MIN = 0.0f;
const float NIGHT_TILT_ANGLE = 5.0f; // 夜间俯仰到此角度

// --- INTERVALS (milliseconds) ---
const unsigned long SOLAR_CALC_INTERVAL = 10000; // 太阳位置/时间同步间隔
const unsigned long SERVO_UPDATE_INTERVAL = 50; // 舵机更新间隔

// --- GLOBAL VARIABLES ---
WiFiServer server(80);
Servo panServo, tiltServo;

float currentPan = 90.0f;
float currentTilt = 45.0f;

// 使用 float 代替 double
struct SolarAngles {
  float azimuth;
  float elevation;
};
SolarAngles lastSolar = {0.0f, 0.0f};

// UTC 时间结构体
struct TimeData {
  int Y = 0, M = 0, D = 0;
  int h = 0, min = 0, s = 0;
  String iso_sync = ""; 
  String toString() const {
    char buf[20];
    sprintf(buf, "%04d-%02d-%02d %02d:%02d:%02d", Y, M, D, h, min, s);
    return String(buf);
  }
};

TimeData g_currentTime = {0, 0, 0, 0, 0, 0, ""};

// Solunar 数据结构体
struct SolunarData {
  String sunrise = "--:--";
  String sunset = "--:--";
  String solarnoon = "--:--";
  int lastFetchDay = 0; 
};
SolunarData dailySolunar;

unsigned long lastSolarCalc = 0;
unsigned long lastServoUpdate = 0;
bool isNightMode = true; 

// --- HELPER FUNCTIONS ---

// 读取 LDR 模拟值 (0-1023)
int readLDR(int pin) { return analogRead(pin); }

// 将方位角转换为舵机水平角 (0-180)
float azimuthToServo(float az_deg) {
  return constrain(az_deg / 2.0f, PAN_MIN, PAN_MAX);
}

// 将高度角转换为舵机俯仰角 (0-90)
float elevationToServo(float el_deg) {
  return constrain(el_deg, TILT_MIN, TILT_MAX);
}

// 角度转弧度 (使用 float)
float deg2rad(float d) { return d * M_PI / 180.0f; }
// 弧度转角度 (使用 float)
float rad2deg(float r) { return r * 180.0f / M_PI; }

// 将 12 小时制时间字符串转换为 24 小时制 (优化：使用 sscanf)
String convert12hTo24h(String time12h) {
  if (time12h.length() < 7) return "--:--";
  
  char buf12h[20];
  time12h.toCharArray(buf12h, 20);

  int hour = 0;
  int minute = 0;
  char ampm[3]; 

  if (sscanf(buf12h, "%d:%d:%*d %2s", &hour, &minute, ampm) != 3) {
      if (sscanf(buf12h, "%d:%d %2s", &hour, &minute, ampm) != 3) {
          return "--:--"; 
      }
  }
  
  bool isPM = (ampm[0] == 'P' || ampm[0] == 'p');
  
  if (isPM && hour < 12) {
    hour += 12;
  } else if (!isPM && hour == 12) {
    hour = 0; 
  }
  
  char buf24h[6];
  sprintf(buf24h, "%02d:%02d", hour, minute);
  return String(buf24h);
}

// --- CORE CALCULATIONS ---

// 计算儒略日 (使用 double 保证精度)
double calcJulianDay(int Y, int M, int D, int h, int m, int s) {
  if (M <= 2) { Y -= 1; M += 12; }
  int A = Y / 100;
  int B = 2 - A + (A / 4);
  double dayFraction = (h + (m + s / 60.0) / 60.0) / 24.0;
  double jd = floor(365.25 * (Y + 4716)) + floor(30.6001 * (M + 1)) + D + dayFraction + B - 1524.5;
  return jd;
}

// 计算太阳在 UTC 时间点的方位角和高度角 (内部使用 double, 结果返回 float)
SolarAngles solarPositionUTC(const TimeData& t, float lat, float lon) {
  double jd = calcJulianDay(t.Y, t.M, t.D, t.h, t.min, t.s);
  double n = jd - 2451545.0;
  double L = fmod(280.460 + 0.9856474 * n, 360.0);
  if (L < 0) L += 360.0;
  double g = fmod(357.528 + 0.9856003 * n, 360.0);
  if (g < 0) g += 360.0;
  double g_rad = deg2rad((float)g);
  double lambda = L + 1.915 * sin(g_rad) + 0.020 * sin(2 * g_rad);
  double lambda_rad = deg2rad((float)lambda);
  double eps = 23.439 - 0.0000004 * n;
  double eps_rad = deg2rad((float)eps);
  double alpha = atan2(cos(eps_rad) * sin(lambda_rad), cos(lambda_rad));
  double delta = asin(sin(eps_rad) * sin(lambda_rad));
  double JD0 = floor(jd + 0.5) - 0.5;
  double T = (JD0 - 2451545.0) / 36525.0;
  double GMST = fmod(280.46061837 + 360.98564736629 * (jd - 2451545.0) + 0.000387933 * T * T - (T * T * T) / 38710000.0, 360.0);
  if (GMST < 0) GMST += 360.0;
  double LST = fmod(GMST + lon, 360.0);
  if (LST < 0) LST += 360.0;
  double alpha_deg = rad2deg((float)alpha); if (alpha_deg < 0) alpha_deg += 360.0;
  double H = LST - alpha_deg; if (H < -180) H += 360; if (H > 180) H -= 360;
  double H_rad = deg2rad((float)H);
  double lat_rad = deg2rad(lat);
  double el_rad = asin(sin(lat_rad) * sin(delta) + cos(lat_rad) * cos(delta) * cos(H_rad));
  double elevation = rad2deg((float)el_rad);
  double az_rad = atan2(sin(H_rad), cos(H_rad) * sin(lat_rad) - tan(delta) * cos(lat_rad));
  double az_deg = rad2deg((float)az_rad) + 180.0;
  if (az_deg < 0) az_deg += 360.0;
  if (az_deg >= 360) az_deg -= 360.0;
  
  SolarAngles out; 
  out.azimuth = (float)az_deg; 
  out.elevation = (float)elevation; 
  return out;
}

// --- NETWORK & API FUNCTIONS ---

// 尝试连接或重连 Wi-Fi 的封装函数
bool attemptReconnect(unsigned long timeout_ms = 15000) {
    if (WiFi.status() == WL_CONNECTED && WiFi.localIP() != IPAddress(0, 0, 0, 0)) {
        return true;
    }
    
    Serial.println("\n尝试 Wi-Fi 重连...");
    WiFi.disconnect();
    WiFi.begin(WIFI_SSID, WIFI_PASS);
    
    unsigned long start = millis();
    while (WiFi.status() != WL_CONNECTED && millis() - start < timeout_ms) {
        delay(500);
        Serial.print("#"); 
    }
    
    if (WiFi.status() == WL_CONNECTED && WiFi.localIP() != IPAddress(0, 0, 0, 0)) {
        Serial.println("\n重连成功. IP: " + WiFi.localIP().toString());
        server.begin(); // 重新开始服务器
        return true;
    }
    
    Serial.println("\nWi-Fi 重连失败。");
    return false;
}
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
